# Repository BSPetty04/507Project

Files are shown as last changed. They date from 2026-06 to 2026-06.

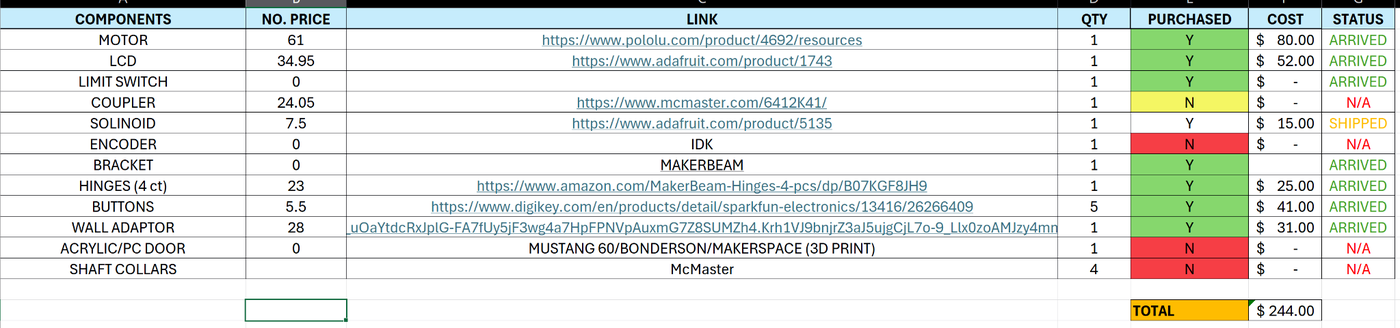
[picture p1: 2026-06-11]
assets/img/bom_budget.png

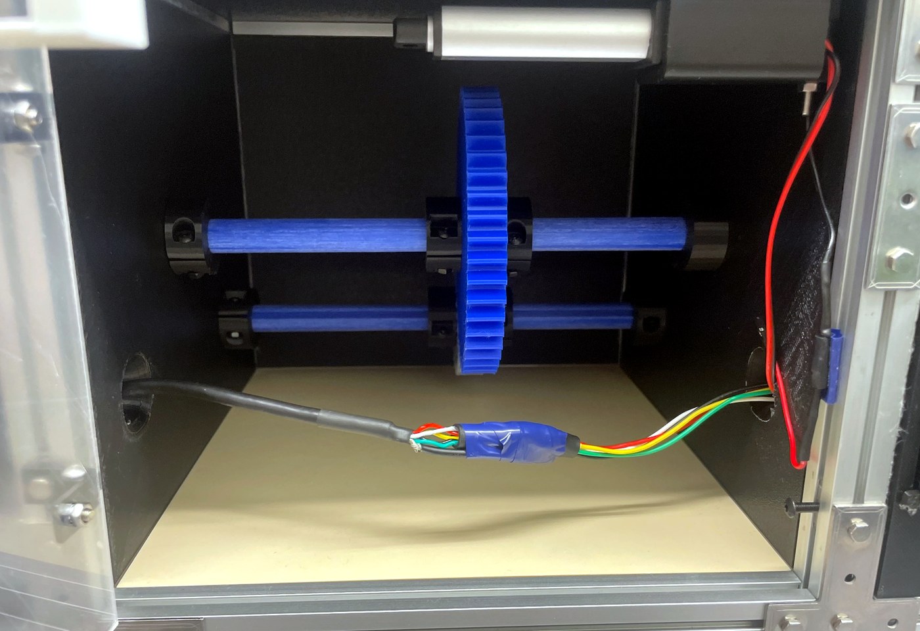
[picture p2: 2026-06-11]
assets/img/prototype_drivetrain.jpg

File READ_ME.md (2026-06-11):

# STM32 Gearbox Controller Term Project

This repository contains the firmware, documentation, and portfolio website for an STM32-based gearbox controller term project. The project combines a custom mechanical gearbox assembly, a custom STM32F411 controller PCB design, encoder speed feedback, actuator locking, user pushbuttons, a TFT display interface, and safety interlocks.

## Portfolio Website

Full project documentation and portfolio website:

[Open the project portfolio website](https://bspetty04.github.io/507Project/)

## Demo Video

A short demonstration video of the gearbox controller prototype is available on YouTube:

[Watch the prototype demo video](https://youtu.be/BHHqBvRPr1w)

## Project Overview

The goal of this project was to design and document a motorized gearbox demonstration system with embedded control. The system is built around an STM32F411 microcontroller and controls a DC motor, actuator/locking mechanism, magnetic door switch, input and output shaft encoders, user buttons, and TFT display.

The main control intent is a safety-supervised speed controller. The user selects an output shaft speed, the firmware reads encoder feedback, and the motor PWM is adjusted using a PI control approach. Safety logic prevents the gearbox from running when the enclosure is open and prevents the actuator lock from moving while the drivetrain is spinning.

## Key Features

- STM32F411-based embedded controller
- Custom PCB schematic and layout design
- 24 V powered system with regulated logic supplies
- DC motor PWM control
- Linear actuator lock/unlock control
- Magnetic door/limit switch safety interlock
- Input shaft and output shaft encoder speed measurement
- Closed-loop PI output shaft speed control
- TFT display for user feedback
- Three-button user interface
- Mechanical gearbox enclosure designed in SolidWorks
- CAD renders, prototype photos, schematics, and firmware documentation

## Control System

The project intelligence is based on three main behaviors:

1. **Closed-loop PI speed control**  
   The selected target output shaft RPM is compared against measured output shaft RPM from the encoder. The speed error is used by a PI controller to adjust motor PWM duty cycle.

2. **Safety interlocks**  
   The motor can only run when the door or magnetic switch indicates that the enclosure is closed. If the door opens while the motor is running, the firmware stops the motor. The actuator lock/unlock function is disabled while the gearbox is running.

3. **User interaction and feedback**  
   The buttons allow the user to start/stop the gearbox, lock/unlock the actuator, and cycle through selectable speed presets. The TFT display is intended to show target RPM, measured input/output RPM, lock state, door state, and fault state.

## Repository Structure

```text
.
├── index.html              # Portfolio homepage
├── hardware.html           # Mechanical hardware documentation
├── electronics.html        # PCB, schematic, and electrical documentation
├── software.html           # Firmware/software architecture
├── control.html            # PI control and safety logic documentation
├── media.html              # Photos, renders, and attachments
├── repository.html         # Repository and build notes
├── style.css               # Website styling
├── assets/                 # Images, schematic renders, and documentation assets
├── repo/                   # Firmware/source-code package
├── README.md               # This file
├── Doxyfile                # Doxygen configuration
└── .gitignore              # Git ignore rules

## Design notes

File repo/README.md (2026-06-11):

# Gearbox Controller Repository

This repository contains the firmware and documentation assets for the STM32F411-based gearbox controller term project.

## Documentation

Open `../index.html` after unzipping the portfolio package, or host the folder with GitHub Pages. The documentation includes mechanical design, custom PCB/schematic overview, firmware architecture, PI speed control, safety interlocks, prototype photos, and bring-up plans.

## Firmware Structure

- `Core/Src/app.c` - top-level state machine and closed-loop PI speed controller
- `Core/Src/motor.c` - PWM and direction control
- `Core/Src/actuator.c` - actuator lock/unlock and fault handling
- `Core/Src/buttons.c` - debounced button events
- `Core/Src/encoders.c` - timer encoder RPM calculations
- `Core/Src/ui.c` - display update interface

## Current Hardware Status

The custom PCB schematic and layout were completed. Physical PCB validation is listed as a next step because the fabricated board had not arrived at the time of documentation.

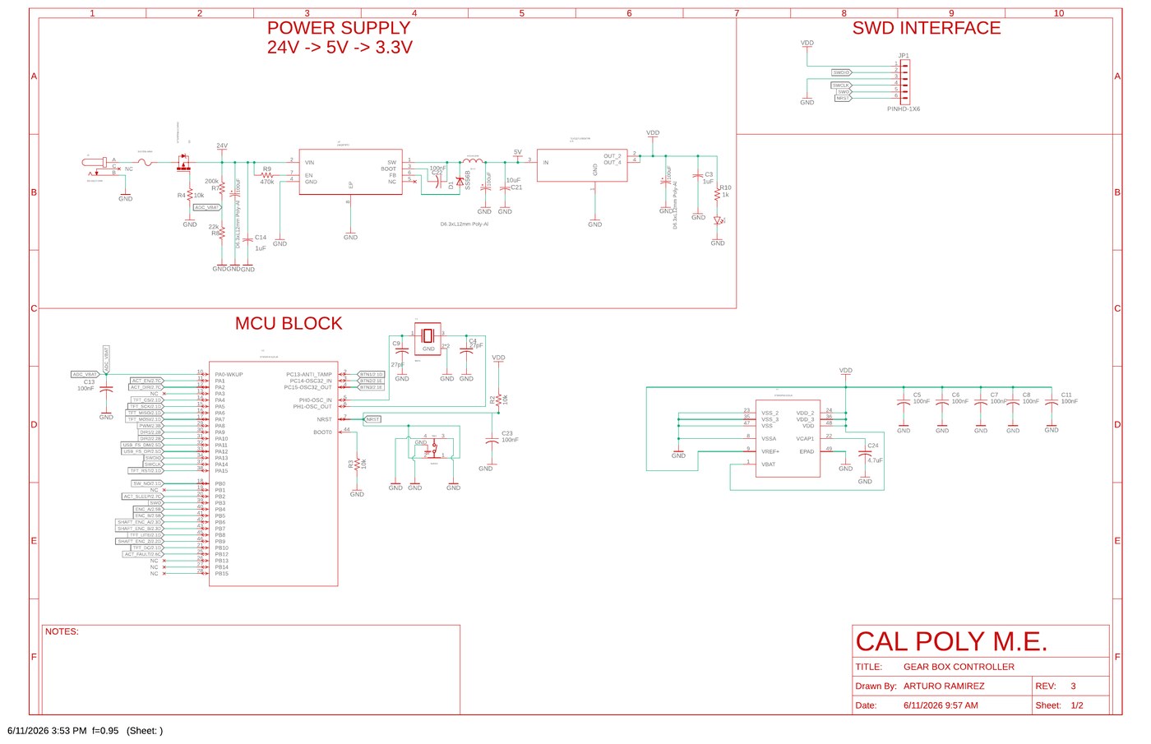
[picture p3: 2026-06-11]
assets/img/schematic_sheet1-1.jpg

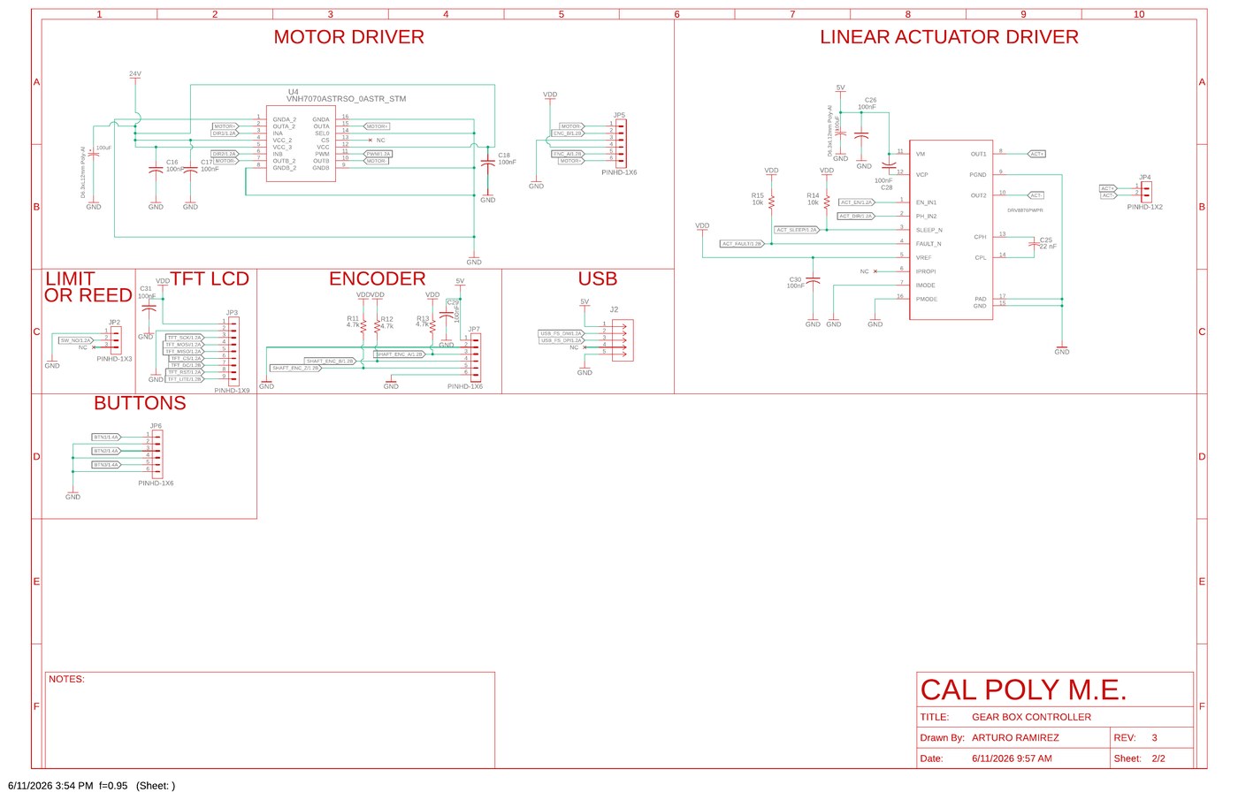
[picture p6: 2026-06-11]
assets/img/schematic_sheet2-1.jpg

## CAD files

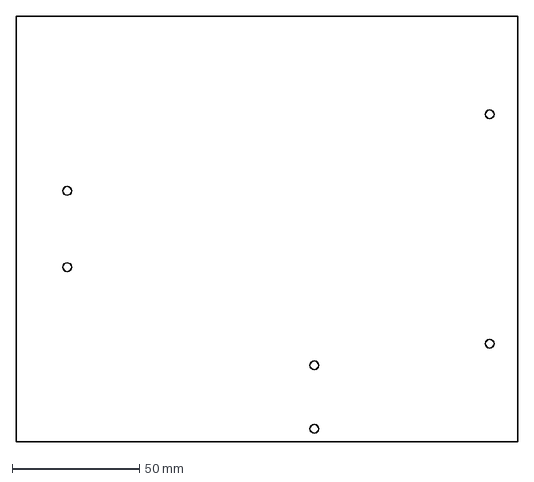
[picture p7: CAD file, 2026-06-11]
assets/docs/Door^WIPAssembly.DXF
197.2 x 167.2 mm

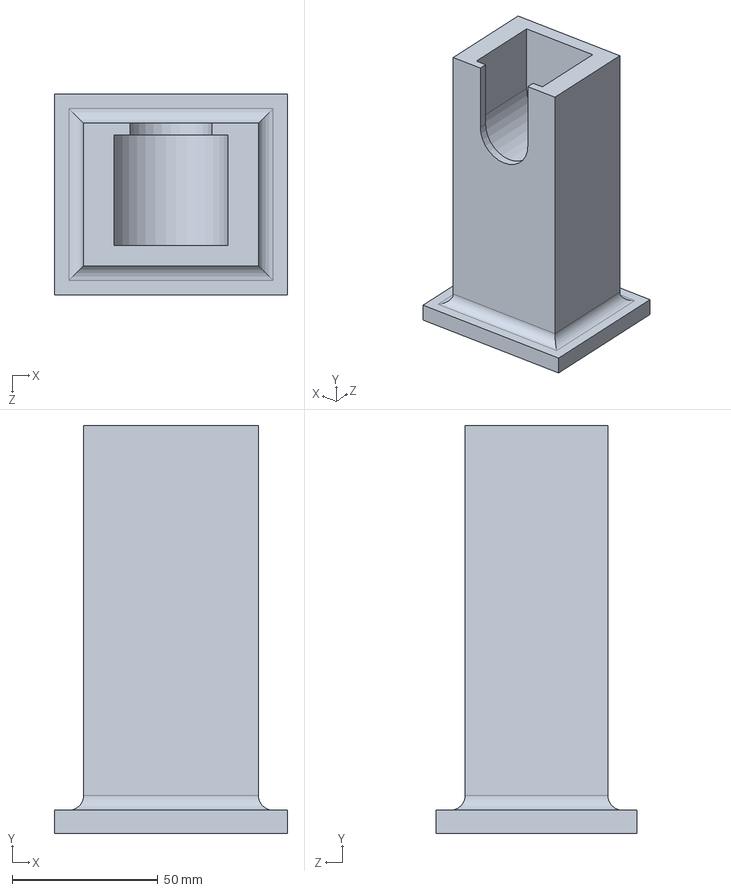
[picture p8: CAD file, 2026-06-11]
assets/docs/EncoderStand.SLDPRT
80.0 x 140.0 x 69.0 mm

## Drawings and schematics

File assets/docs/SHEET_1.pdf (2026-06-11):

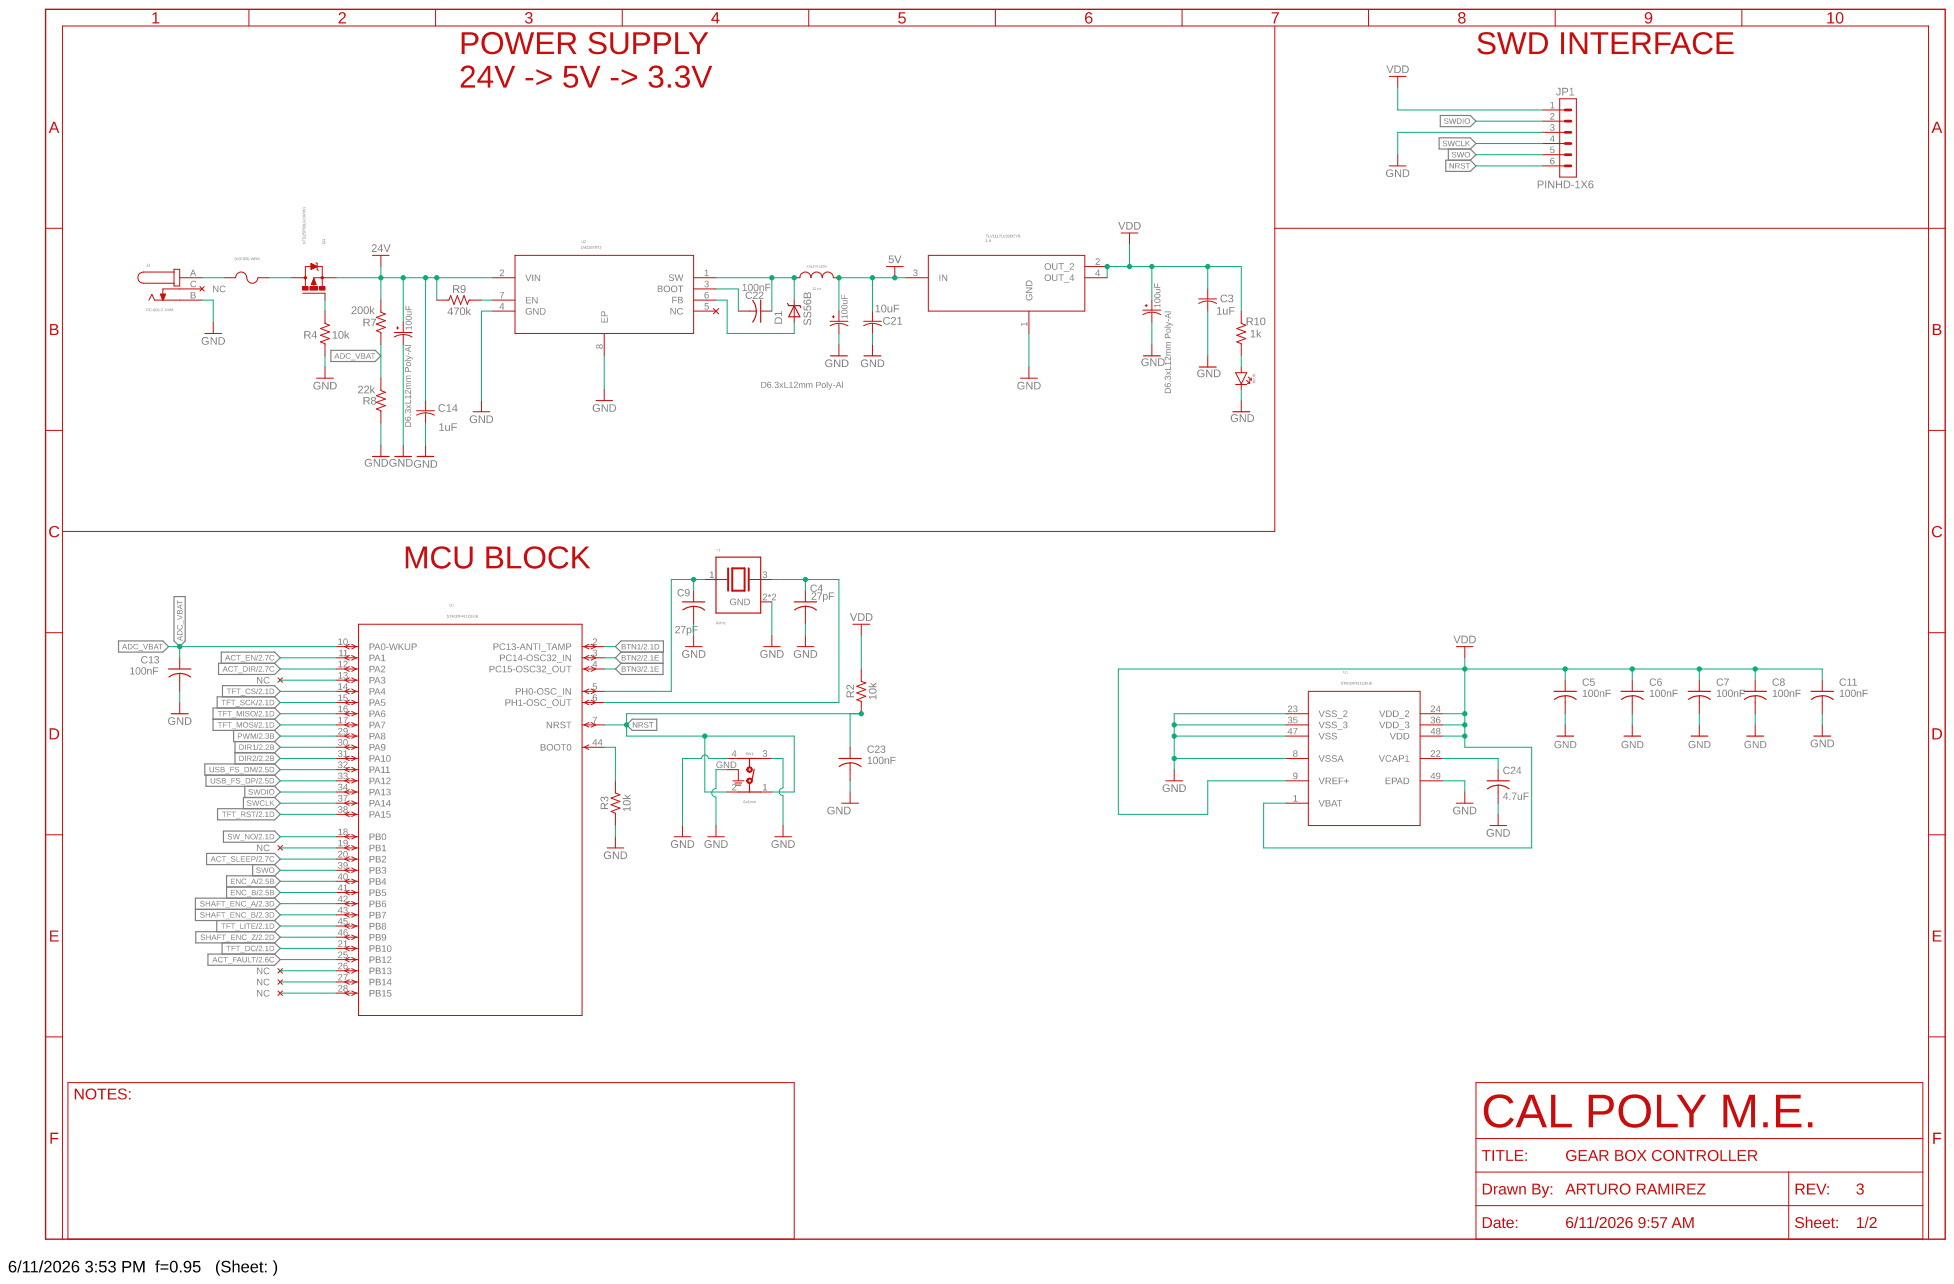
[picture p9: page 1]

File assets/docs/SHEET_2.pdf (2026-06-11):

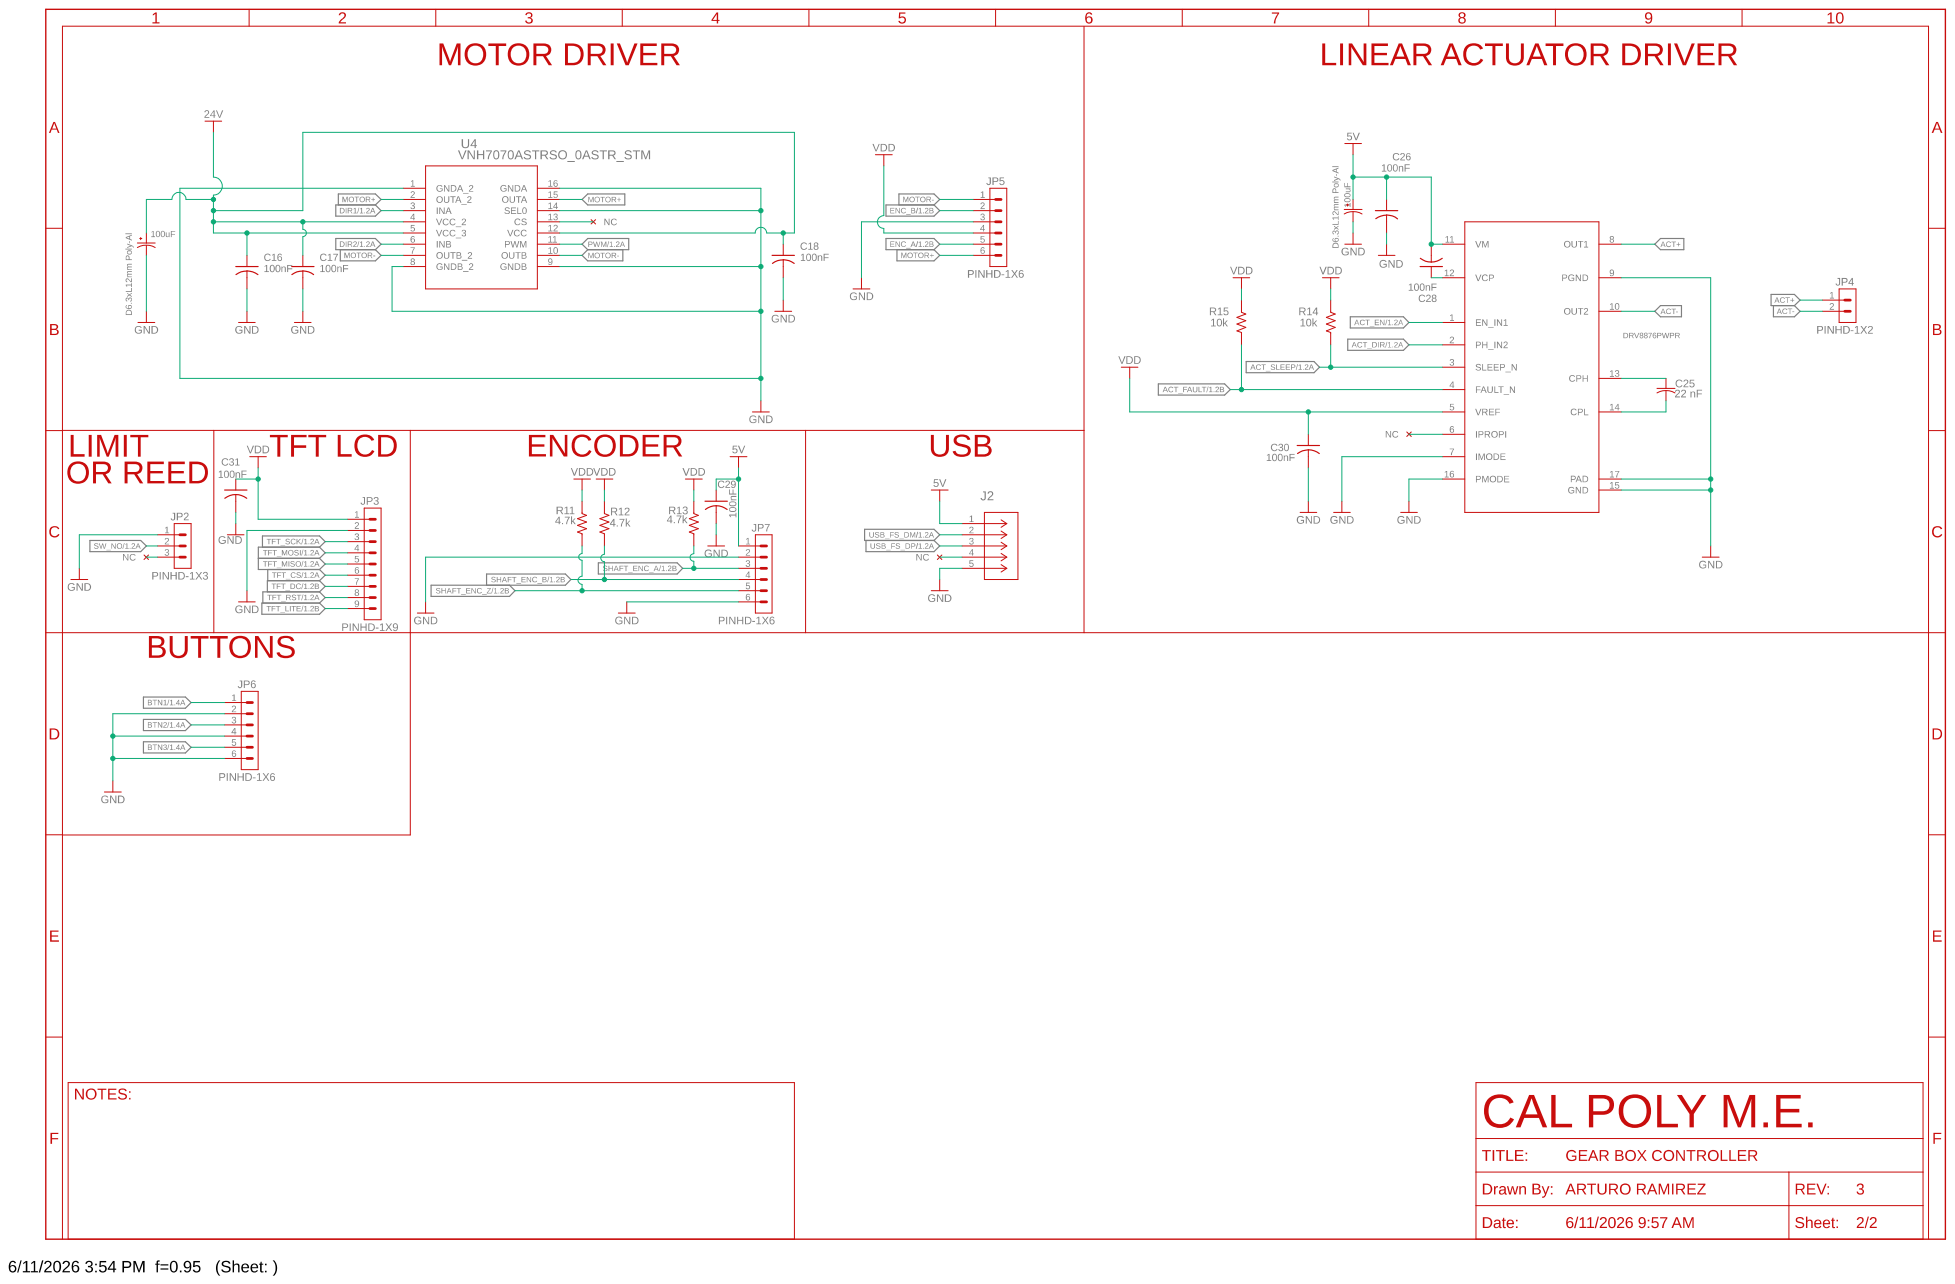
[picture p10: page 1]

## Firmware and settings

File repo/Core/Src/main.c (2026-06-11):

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

/* Includes ------------------------------------------------------------------*/
#include "main.h"
#include "usb_device.h"

/* USER CODE BEGIN Includes */
#include <stdio.h>
#include <stdbool.h>
#include <string.h>
/* USER CODE END Includes */

/* USER CODE BEGIN PTD */

typedef enum
{
  SYS_STOPPED_LOCKED = 0,
  SYS_STOPPED_UNLOCKED,
  SYS_RUNNING,
  SYS_FAULT
} SystemState_t;

typedef enum
{
  BTN_START_STOP = 0,
  BTN_LOCK_UNLOCK,
  BTN_SPEED_TOGGLE,
  BTN_COUNT
} ButtonId_t;

typedef struct
{
  GPIO_TypeDef *port;
  uint16_t pin;
  GPIO_PinState stable_state;
  GPIO_PinState last_raw_state;
  uint32_t last_change_ms;
  bool pressed_event;
} Button_t;

/* USER CODE END PTD */

/* USER CODE BEGIN PD */

#define PWM_MAX_DUTY                 999

#define BUTTON_DEBOUNCE_MS           40
#define DISPLAY_UPDATE_MS            250
#define ENCODER_SAMPLE_MS            100

// Change these later when you know your encoder specs.
// If your encoder is 600 PPR and timer counts x4, use 2400.
#define MOTOR_ENCODER_COUNTS_PER_REV 1024.0f
#define SHAFT_ENCODER_COUNTS_PER_REV 1024.0f

// Assumptions:
// Buttons active-low: pressed = GPIO_PIN_RESET
// Door switch active-low: closed = GPIO_PIN_RESET
// ACT_FAULT active-low: fault = GPIO_PIN_RESET
#define BUTTON_PRESSED_STATE         GPIO_PIN_RESET
#define DOOR_CLOSED_STATE            GPIO_PIN_RESET
#define ACT_FAULT_ACTIVE_STATE       GPIO_PIN_RESET

/* USER CODE END PD */

ADC_HandleTypeDef hadc1;
SPI_HandleTypeDef hspi1;
TIM_HandleTypeDef htim1;
TIM_HandleTypeDef htim3;
TIM_HandleTypeDef htim4;

/* USER CODE BEGIN PV */

static SystemState_t system_state = SYS_STOPPED_LOCKED;

static const uint16_t speed_rpm_options[] = {50, 100, 150, 200, 250};
static const uint16_t pwm_duty_options[]  = {200, 350, 500, 650, 800};

static const uint8_t num_speed_options = sizeof(speed_rpm_options) / sizeof(speed_rpm_options[0]);
static uint8_t selected_speed_index = 0;

static Button_t buttons[BTN_COUNT];

static int16_t last_motor_count = 0;
static int16_t last_shaft_count = 0;
static float motor_rpm = 0.0f;
static float shaft_rpm = 0.0f;
static uint32_t last_encoder_sample_ms = 0;

static uint32_t last_display_update_ms = 0;

/* USER CODE END PV */

void SystemClock_Config(void);
static void MX_GPIO_Init(void);
static void MX_ADC1_Init(void);
static void MX_SPI1_Init(void);
static void MX_TIM1_Init(void);
static void MX_TIM3_Init(void);
static void MX_TIM4_Init(void);

/* USER CODE BEGIN PFP */

static void App_Init(void);
static void App_Update(void);

static void Buttons_Init(void);
static void Buttons_Update(void);
static bool Button_WasPressed(ButtonId_t button);

static bool Door_IsClosed(void);
static bool Actuator_HasFault(void);

static void Motor_Init(void);
static void Motor_Stop(void);
static void Motor_StartSelectedSpeed(void);
static void Motor_SetDuty(uint16_t duty);

static void Actuator_Init(void);
static void Actuator_Stop(void);
static void Actuator_Lock(void);
static void Actuator_Unlock(void);

static void Encoders_Init(void);
static void Encoders_Update(void);

static void Display_Update(void);

/* USER CODE END PFP */

/**
  * @brief  The application entry point.
  * @retval int
  */
int main(void)
{
  HAL_Init();

  SystemClock_Config();

  MX_GPIO_Init();
  MX_ADC1_Init();
  MX_SPI1_Init();
  MX_TIM1_Init();
  MX_TIM3_Init();
  MX_TIM4_Init();
  MX_USB_DEVICE_Init();

  /* USER CODE BEGIN 2 */
  App_Init();
  /* USER CODE END 2 */

  while (1)
  {
    /* USER CODE BEGIN 3 */
    App_Update();
    HAL_Delay(5);
    /* USER CODE END 3 */
  }
}

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
/* USER CODE BEGIN 4 */

static void App_Init(void)
{
  Buttons_Init();
  Motor_Init();
  Actuator_Init();
  Encoders_Init();

  system_state = SYS_STOPPED_LOCKED;
  last_display_update_ms = HAL_GetTick();
}

static void App_Update(void)
{
  Buttons_Update();
  Encoders_Update();

  bool door_closed = Door_IsClosed();
  bool fault = Actuator_HasFault();

  if (fault)
  {
    Motor_Stop();
    Actuator_Stop();
    system_state = SYS_FAULT;
  }

  if (!door_closed && system_state == SYS_RUNNING)
  {
    Motor_Stop();
    system_state = SYS_STOPPED_LOCKED;
  }

  if (Button_WasPressed(BTN_SPEED_TOGGLE))
  {
    if (system_state != SYS_RUNNING)
    {
      selected_speed_index++;

      if (selected_speed_index >= num_speed_options)
      {
        selected_speed_index = 0;
      }
    }
  }

  if (Button_WasPressed(BTN_START_STOP))
  {
    if (system_state == SYS_RUNNING)
    {
      Motor_Stop();
      system_state = SYS_STOPPED_LOCKED;
    }
    else if (system_state == SYS_STOPPED_LOCKED || system_state == SYS_STOPPED_UNLOCKED)
    {
      if (door_closed && !fault)
      {
        Motor_StartSelectedSpeed();
        system_state = SYS_RUNNING;
      }
    }
    else if (system_state == SYS_FAULT)
    {
      if (!fault)
      {
        system_state = SYS_STOPPED_LOCKED;
      }
    }
  }

  if (Button_WasPressed(BTN_LOCK_UNLOCK))
  {
    // Safety: actuator cannot lock/unlock while motor is running.
    if (system_state != SYS_RUNNING && system_state != SYS_FAULT)
    {
      if (system_state == SYS_STOPPED_LOCKED)
      {
        Actuator_Unlock();
        system_state = SYS_STOPPED_UNLOCKED;
      }
      else
      {
        Actuator_Lock();
        system_state = SYS_STOPPED_LOCKED;
      }

      // Simple actuator pulse.
      // Increase this if the actuator needs more time.
      HAL_Delay(250);
      Actuator_Stop();
    }
  }

  Display_Update();
}

static void Buttons_Init(void)
{
  buttons[BTN_START_STOP].port = BTN1_GPIO_Port;
  buttons[BTN_START_STOP].pin = BTN1_Pin;

  buttons[BTN_LOCK_UNLOCK].port = BTN2_GPIO_Port;
  buttons[BTN_LOCK_UNLOCK].pin = BTN2_Pin;

  buttons[BTN_SPEED_TOGGLE].port = BTN3_GPIO_Port;
  buttons[BTN_SPEED_TOGGLE].pin = BTN3_Pin;

  for (uint8_t i = 0; i < BTN_COUNT; i++)
  {
    GPIO_PinState raw = HAL_GPIO_ReadPin(buttons[i].port, buttons[i].pin);

    buttons[i].stable_state = raw;
    buttons[i].last_raw_state = raw;
    buttons[i].last_change_ms = HAL_GetTick();
    buttons[i].pressed_event = false;
  }
}

static void Buttons_Update(void)
{
  uint32_t now = HAL_GetTick();

  for (uint8_t i = 0; i < BTN_COUNT; i++)
  {
    GPIO_PinState raw = HAL_GPIO_ReadPin(buttons[i].port, buttons[i].pin);

    if (raw != buttons[i].last_raw_state)
    {
      buttons[i].last_raw_state = raw;
      buttons[i].last_change_ms = now;
    }

    if ((now - buttons[i].last_change_ms) >= BUTTON_DEBOUNCE_MS)
    {
      if (raw != buttons[i].stable_state)
      {
        GPIO_PinState old_state = buttons[i].stable_state;
        buttons[i].stable_state = raw;

        if (old_state != BUTTON_PRESSED_STATE && raw == BUTTON_PRESSED_STATE)
        {
          buttons[i].pressed_event = true;
        }
      }
    }
  }
}

static bool Button_WasPressed(ButtonId_t button)
{
  if (button >= BTN_COUNT)
  {
    return false;
  }

  bool was_pressed = buttons[button].pressed_event;
  buttons[button].pressed_event = false;

  return was_pressed;
}

static bool Door_IsClosed(void)
{
  return HAL_GPIO_ReadPin(SW_NO_GPIO_Port, SW_NO_Pin) == DOOR_CLOSED_STATE;
}

static bool Actuator_HasFault(void)
{
  return HAL_GPIO_ReadPin(ACT_FAULT_GPIO_Port, ACT_FAULT_Pin) == ACT_FAULT_ACTIVE_STATE;
}

static void Motor_Init(void)
{
  HAL_TIM_PWM_Start(&htim1, TIM_CHANNEL_1);
  Motor_Stop();
}

static void Motor_SetDuty(uint16_t duty)
{
  if (duty > PWM_MAX_DUTY)
  {
    duty = PWM_MAX_DUTY;
  }

  __HAL_TIM_SET_COMPARE(&htim1, TIM_CHANNEL_1, duty);
}

static void Motor_StartSelectedSpeed(void)
{
  // Direction assumption: DIR1 high, DIR2 low = forward.
  HAL_GPIO_WritePin(DIR1_GPIO_Port, DIR1_Pin, GPIO_PIN_SET);
  HAL_GPIO_WritePin(DIR2_GPIO_Port, DIR2_Pin, GPIO_PIN_RESET);

  Motor_SetDuty(pwm_duty_options[selected_speed_index]);
}

static void Motor_Stop(void)
{
  Motor_SetDuty(0);

  // Coast/stop assumption: both direction pins low.
  HAL_GPIO_WritePin(DIR1_GPIO_Port, DIR1_Pin, GPIO_PIN_RESET);
  HAL_GPIO_WritePin(DIR2_GPIO_Port, DIR2_Pin, GPIO_PIN_RESET);
}

static void Actuator_Init(void)
{
  // Assumption: ACT_SLEEP high = actuator driver awake.
  HAL_GPIO_WritePin(ACT_SLEEP_GPIO_Port, ACT_SLEEP_Pin, GPIO_PIN_SET);
  Actuator_Stop();
}

static void Actuator_Stop(void)
{
  HAL_GPIO_WritePin(ACT_EN_GPIO_Port, ACT_EN_Pin, GPIO_PIN_RESET);
}

static void Actuator_Lock(void)
{
  if (Actuator_HasFault())
  {
    Actuator_Stop();
    system_state = SYS_FAULT;
    return;
  }

  // Assumption: ACT_DIR low = lock.
  HAL_GPIO_WritePin(ACT_DIR_GPIO_Port, ACT_DIR_Pin, GPIO_PIN_RESET);
  HAL_GPIO_WritePin(ACT_EN_GPIO_Port, ACT_EN_Pin, GPIO_PIN_SET);
}

static void Actuator_Unlock(void)
{
  if (Actuator_HasFault())
  {
    Actuator_Stop();
    system_state = SYS_FAULT;
    return;
  }

  // Assumption: ACT_DIR high = unlock.
  HAL_GPIO_WritePin(ACT_DIR_GPIO_Port, ACT_DIR_Pin, GPIO_PIN_SET);
  HAL_GPIO_WritePin(ACT_EN_GPIO_Port, ACT_EN_Pin, GPIO_PIN_SET);
}

static void Encoders_Init(void)
{
  HAL_TIM_Encoder_Start(&htim3, TIM_CHANNEL_ALL);
  HAL_TIM_Encoder_Start(&htim4, TIM_CHANNEL_ALL);

  __HAL_TIM_SET_COUNTER(&htim3, 0);
  __HAL_TIM_SET_COUNTER(&htim4, 0);

  last_motor_count = 0;
  last_shaft_count = 0;
  last_encoder_sample_ms = HAL_GetTick();
}

static void Encoders_Update(void)
{
  uint32_t now = HAL_GetTick();

  if ((now - last_encoder_sample_ms) < ENCODER_SAMPLE_MS)
  {
    return;
  }

  float dt_minutes = (float)(now - last_encoder_sample_ms) / 60000.0f;

  int16_t motor_count = (int16_t)__HAL_TIM_GET_COUNTER(&htim3);
  int16_t shaft_count = (int16_t)__HAL_TIM_GET_COUNTER(&htim4);

  int16_t motor_delta = motor_count - last_motor_count;
  int16_t shaft_delta = shaft_count - last_shaft_count;

  motor_rpm = ((float)motor_delta / MOTOR_ENCODER_COUNTS_PER_REV) / dt_minutes;
  shaft_rpm = ((float)shaft_delta / SHAFT_ENCODER_COUNTS_PER_REV) / dt_minutes;

  last_motor_count = motor_count;
  last_shaft_count = shaft_count;
  last_encoder_sample_ms = now;
}

static void Display_Update(void)
{
  uint32_t now = HAL_GetTick();

  if ((now - last_display_update_ms) < DISPLAY_UPDATE_MS)
  {
    return;
  }

  last_display_update_ms = now;

  // Placeholder until TFT driver is added.
  // For now, just keep TFT backlight on.
  HAL_GPIO_WritePin(TFT_LITE_GPIO_Port, TFT_LITE_Pin, GPIO_PIN_SET);

  // Variables available for display later:
  // speed_rpm_options[selected_speed_index]
  // motor_rpm
  // shaft_rpm
  // system_state
  // Door_IsClosed()
  // Actuator_HasFault()

  (void)motor_rpm;
  (void)shaft_rpm;
}

/* USER CODE END 4 */
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


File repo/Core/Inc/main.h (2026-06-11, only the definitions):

#define BTN1_Pin GPIO_PIN_13
#define BTN1_GPIO_Port GPIOC
#define BTN2_Pin GPIO_PIN_14
#define BTN2_GPIO_Port GPIOC
#define BTN3_Pin GPIO_PIN_15
#define BTN3_GPIO_Port GPIOC
#define OSC_IN_Pin GPIO_PIN_0
#define OSC_IN_GPIO_Port GPIOH
#define OSC_OUT_Pin GPIO_PIN_1
#define OSC_OUT_GPIO_Port GPIOH
#define ADC_24V_Pin GPIO_PIN_0
#define ADC_24V_GPIO_Port GPIOA
#define ACT_EN_Pin GPIO_PIN_1
#define ACT_EN_GPIO_Port GPIOA
#define ACT_DIR_Pin GPIO_PIN_2
#define ACT_DIR_GPIO_Port GPIOA
#define TFT_CS_Pin GPIO_PIN_4
#define TFT_CS_GPIO_Port GPIOA
#define TFT_SCK_Pin GPIO_PIN_5
#define TFT_SCK_GPIO_Port GPIOA
#define TFT_MISO_Pin GPIO_PIN_6
#define TFT_MISO_GPIO_Port GPIOA
#define TFT_MOSI_Pin GPIO_PIN_7
#define TFT_MOSI_GPIO_Port GPIOA
#define SW_NO_Pin GPIO_PIN_0
#define SW_NO_GPIO_Port GPIOB
#define SW_NO_EXTI_IRQn EXTI0_IRQn
#define ACT_SLEEP_Pin GPIO_PIN_2
#define ACT_SLEEP_GPIO_Port GPIOB
#define TFT_DC_Pin GPIO_PIN_10
#define TFT_DC_GPIO_Port GPIOB
#define ACT_FAULT_Pin GPIO_PIN_12
#define ACT_FAULT_GPIO_Port GPIOB
#define PWM_Pin GPIO_PIN_8
#define PWM_GPIO_Port GPIOA
#define DIR1_Pin GPIO_PIN_9
#define DIR1_GPIO_Port GPIOA
#define DIR2_Pin GPIO_PIN_10
#define DIR2_GPIO_Port GPIOA
#define USB_D__Pin GPIO_PIN_11
#define USB_D__GPIO_Port GPIOA
#define USB_D_A12_Pin GPIO_PIN_12
#define USB_D_A12_GPIO_Port GPIOA
#define SWDIO_Pin GPIO_PIN_13
#define SWDIO_GPIO_Port GPIOA
#define SWDCLK_Pin GPIO_PIN_14
#define SWDCLK_GPIO_Port GPIOA
#define TFT_RST_Pin GPIO_PIN_15
#define TFT_RST_GPIO_Port GPIOA
#define SWO_Pin GPIO_PIN_3
#define SWO_GPIO_Port GPIOB
#define ENC_A_Pin GPIO_PIN_4
#define ENC_A_GPIO_Port GPIOB
#define ENC_B_Pin GPIO_PIN_5
#define ENC_B_GPIO_Port GPIOB
#define SHAFT_ENC_A_Pin GPIO_PIN_6
#define SHAFT_ENC_A_GPIO_Port GPIOB
#define SHAFT_ENC_B_Pin GPIO_PIN_7
#define SHAFT_ENC_B_GPIO_Port GPIOB
#define TFT_LITE_Pin GPIO_PIN_8
#define TFT_LITE_GPIO_Port GPIOB
#define SHAFT_ENC_Z_Pin GPIO_PIN_9
#define SHAFT_ENC_Z_GPIO_Port GPIOB
#define SHAFT_ENC_Z_EXTI_IRQn EXTI9_5_IRQn

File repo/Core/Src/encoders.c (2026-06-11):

#include "encoders.h"
#include "tim.h"

#define ENCODER_SAMPLE_MS       100

// Update these once you know your encoder counts per revolution.
// For quadrature x4 counting, effective counts may be PPR * 4.
#define MOTOR_ENCODER_COUNTS_PER_REV  1024.0f
#define SHAFT_ENCODER_COUNTS_PER_REV  1024.0f

static int16_t last_motor_count = 0;
static int16_t last_shaft_count = 0;

static float motor_rpm = 0.0f;
static float shaft_rpm = 0.0f;

static uint32_t last_sample_ms = 0;

void Encoders_Init(void)
{
    HAL_TIM_Encoder_Start(&htim3, TIM_CHANNEL_ALL);
    HAL_TIM_Encoder_Start(&htim4, TIM_CHANNEL_ALL);

    __HAL_TIM_SET_COUNTER(&htim3, 0);
    __HAL_TIM_SET_COUNTER(&htim4, 0);

    last_motor_count = 0;
    last_shaft_count = 0;
    last_sample_ms = HAL_GetTick();
}

void Encoders_Update(void)
{
    uint32_t now = HAL_GetTick();

    if ((now - last_sample_ms) < ENCODER_SAMPLE_MS)
    {
        return;
    }

    float dt_minutes = (float)(now - last_sample_ms) / 60000.0f;

    int16_t motor_count = (int16_t)__HAL_TIM_GET_COUNTER(&htim3);
    int16_t shaft_count = (int16_t)__HAL_TIM_GET_COUNTER(&htim4);

    int16_t motor_delta = motor_count - last_motor_count;
    int16_t shaft_delta = shaft_count - last_shaft_count;

    motor_rpm = ((float)motor_delta / MOTOR_ENCODER_COUNTS_PER_REV) / dt_minutes;
    shaft_rpm = ((float)shaft_delta / SHAFT_ENCODER_COUNTS_PER_REV) / dt_minutes;

    last_motor_count = motor_count;
    last_shaft_count = shaft_count;
    last_sample_ms = now;
}

float Encoders_GetMotorRPM(void)
{
    return motor_rpm;
}

float Encoders_GetShaftRPM(void)
{
    return shaft_rpm;
}

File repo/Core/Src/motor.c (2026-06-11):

#include "motor.h"
#include "tim.h"

#define MOTOR_PWM_TIMER      htim1
#define MOTOR_PWM_CHANNEL    TIM_CHANNEL_1
#define MOTOR_PWM_MAX        999

static bool motor_running = false;

void Motor_Init(void)
{
    HAL_TIM_PWM_Start(&MOTOR_PWM_TIMER, MOTOR_PWM_CHANNEL);
    Motor_Stop();
}

void Motor_SetForward(void)
{
    // Adjust these if your motor driver direction logic is different.
    HAL_GPIO_WritePin(DIR1_GPIO_Port, DIR1_Pin, GPIO_PIN_SET);
    HAL_GPIO_WritePin(DIR2_GPIO_Port, DIR2_Pin, GPIO_PIN_RESET);
}

void Motor_SetDuty(uint16_t duty)
{
    if (duty > MOTOR_PWM_MAX)
    {
        duty = MOTOR_PWM_MAX;
    }

    __HAL_TIM_SET_COMPARE(&MOTOR_PWM_TIMER, MOTOR_PWM_CHANNEL, duty);

    motor_running = duty > 0;
}

void Motor_Stop(void)
{
    __HAL_TIM_SET_COMPARE(&MOTOR_PWM_TIMER, MOTOR_PWM_CHANNEL, 0);

    // Optional brake/coast behavior.
    // This setup makes both direction pins low.
    HAL_GPIO_WritePin(DIR1_GPIO_Port, DIR1_Pin, GPIO_PIN_RESET);
    HAL_GPIO_WritePin(DIR2_GPIO_Port, DIR2_Pin, GPIO_PIN_RESET);

    motor_running = false;
}

bool Motor_IsRunning(void)
{
    return motor_running;
}

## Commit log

2026-06-11 Add files via upload
    Initial portfolio documentation upload
    [Door^WIPAssembly.DXF, EncoderStand.SLDPRT]
2026-06-11 Add files via upload
    Supp. Material
    [Door^WIPAssembly.DXF, EncoderStand.SLDPRT]

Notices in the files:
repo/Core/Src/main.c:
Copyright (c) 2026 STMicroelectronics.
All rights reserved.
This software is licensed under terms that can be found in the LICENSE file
